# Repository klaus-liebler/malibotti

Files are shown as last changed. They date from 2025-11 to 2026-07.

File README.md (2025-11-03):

# Malibotti
Malibotti represents my initial effort to develop a drawing robot, building upon the concepts of the [ESP32-Drawing-Robot project](https://github.com/MatixYo/ESP32-Drawing-Robot). Key differentiators include a reduced reliance on 3D-printed parts and a custom PCB that functions dually as an electronic carrier and a mechanical structure. Additionally, a dedicated daughterboard with high-precision Hall-effect sensors provides servo arm position data, facilitating closed-loop feedback control for 360° servos.





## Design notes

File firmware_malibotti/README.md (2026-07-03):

# Firmware for Malibotti with 28-BYJ48 stepper motors

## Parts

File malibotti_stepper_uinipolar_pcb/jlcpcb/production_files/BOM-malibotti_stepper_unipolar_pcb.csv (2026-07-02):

Comment | Designator | Footprint | LCSC | Quantity
100R | R2 | R_0805_2012Metric_Pad1.20x1.40mm_HandSolder | C17408 | 1
22R | R8,R9 | R_0402_1005Metric | C25092 | 2
22u | C12,C5,C6 | C_0805_2012Metric | C45783 | 3
5k1 | R1,R26,R3,R4,R7 | R_0402_1005Metric | C25905 | 5
AMS1117 | U3 | SOT-223-3_TabPin2 | C6186 | 1
BTN | SW8 | SW_Push_1P1T_NO_6x6mm_H6.5mm_Reverse | C541960 | 1
Buzzer | BZ1 | XDCR_CMT-7525-80-SMT-TR_handsolder | C49246950 | 1
ESP32-S3-MINI-1 | U5 | ESP32-S2-MINI-1 | C2913206 | 1
RGB3 | D21 | SK6812MINI-E_REV | C5149201 | 1
RST | SW1 | SW_Push_1P1T_NO_6x6mm_H6.5mm_Reverse | C541960 | 1
Servo | J3 | PinHeader_1x03_P2.54mm_Vertical_SMD_Pin1Left | C5160786 | 1
Stepper 1 | J1 | JST_XH_5P_SMD | C7429683 | 1
Stepper 2 | J2 | JST_XH_5P_SMD | C7429683 | 1
TBD62783A | U1 | SSOP-18_4.4x6.5mm_P0.65mm | C4153829 | 1
USB_C_Receptacle_USB2.0_16P | J5 | USB_C_Receptacle_HRO_TYPE-C-31-M-12 | C165948 | 1
u1 | C10,C11,C3,C9 | C_0402_1005Metric | C1525 | 4
MicroSwitchLeft | SW2 | Omron D2F Left Angled |  | 1
Serial | J6 | JST_XH_S4B-XH-A-1_1x04_P2.50mm_Horizontal_SmallerCourtyard |  | 1
MicroSwitchRight | SW3 | Omron D2F Right Angled |  | 1
I2C | J4 | JST_XH_S4B-XH-A-1_1x04_P2.50mm_Horizontal_SmallerCourtyard |  | 1

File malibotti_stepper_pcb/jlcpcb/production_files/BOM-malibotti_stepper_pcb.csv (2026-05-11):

Comment | Designator | Footprint | LCSC | Quantity
100R | R2 | R_0805_2012Metric_Pad1.20x1.40mm_HandSolder | C17408 | 1
10k | R10,R19,R22,R23 | R_0402_1005Metric | C25744 | 4
1k | R11,R12,R13,R14,R15,R16,R17,R18 | R_0402_1005Metric | C11702 | 8
1n | C10,C13,C14,C9 | C_0402_1005Metric | C1523 | 4
1r0 | R20,R21,R5,R6 | R_0805_2012Metric_Pad1.20x1.40mm_HandSolder | C25271 | 4
1u | C1,C4 | C_0402_1005Metric | C52923 | 2
22R | R8,R9 | R_0402_1005Metric | C25092 | 2
22n | C16,C7 | C_0402_1005Metric | C1532 | 2
22u | C12,C17,C2,C5 | C_0805_2012Metric | C45783 | 4
2u2 | C18,C6 | C_0603_1608Metric | C23630 | 2
4k7 | R3,R4 | R_0402_1005Metric | C25900 | 2
5k1 | R1,R24,R25,R7 | R_0402_1005Metric | C25905 | 4
BTN | SW8 | SW_Push_1P1T_NO_6x6mm_H6.5mm_Reverse | C541960 | 1
Buzzer | BZ1 | XDCR_CMT-7525-80-SMT-TR_handsolder | C49246950 | 1
ESP32-C3-MINI-1 | U1 | ESP32-C3-MINI-1 | C2838502 | 1
RGB3 | D21 | SK6812MINI-E_REV | C5149201 | 1
RST | SW1 | SW_Push_1P1T_NO_6x6mm_H6.5mm_Reverse | C541960 | 1
STSPIN220 | U3,U4 | VQFN-16-1EP_3x3mm_P0.5mm_EP1.8x1.8mm | C2150516 | 2
Servo | J3 | PinHeader_1x03_P2.54mm_Vertical_SMD_Pin1Left | C5160786 | 1
Stepper 1 | J1,J2 | JST_XH_5P_SMD | C7429683 | 2
USB_C_Receptacle_USB2.0_16P | J5 | USB_C_Receptacle_HRO_TYPE-C-31-M-12 | C165948 | 1
XC6206PxxxMR | U2 | SOT-23-3 | C5446 | 1
u1 | C11,C15,C3,C8 | C_0402_1005Metric | C1525 | 4
MicroSwitchLeft | SW2 | Omron D2F Left Angled |  | 1
Conn_01x04 | J6 | JST_XH_S4B-XH-A-1_1x04_P2.50mm_Horizontal_SmallerCourtyard |  | 1
MicroSwitchRight | SW3 | Omron D2F Right Angled |  | 1
Conn_01x04 | J4 | JST_XH_S4B-XH-A-1_1x04_P2.50mm_Horizontal_SmallerCourtyard |  | 1
TestPoint | TP1 | TestPoint_THTPad_D1.0mm_Drill0.5mm |  | 1

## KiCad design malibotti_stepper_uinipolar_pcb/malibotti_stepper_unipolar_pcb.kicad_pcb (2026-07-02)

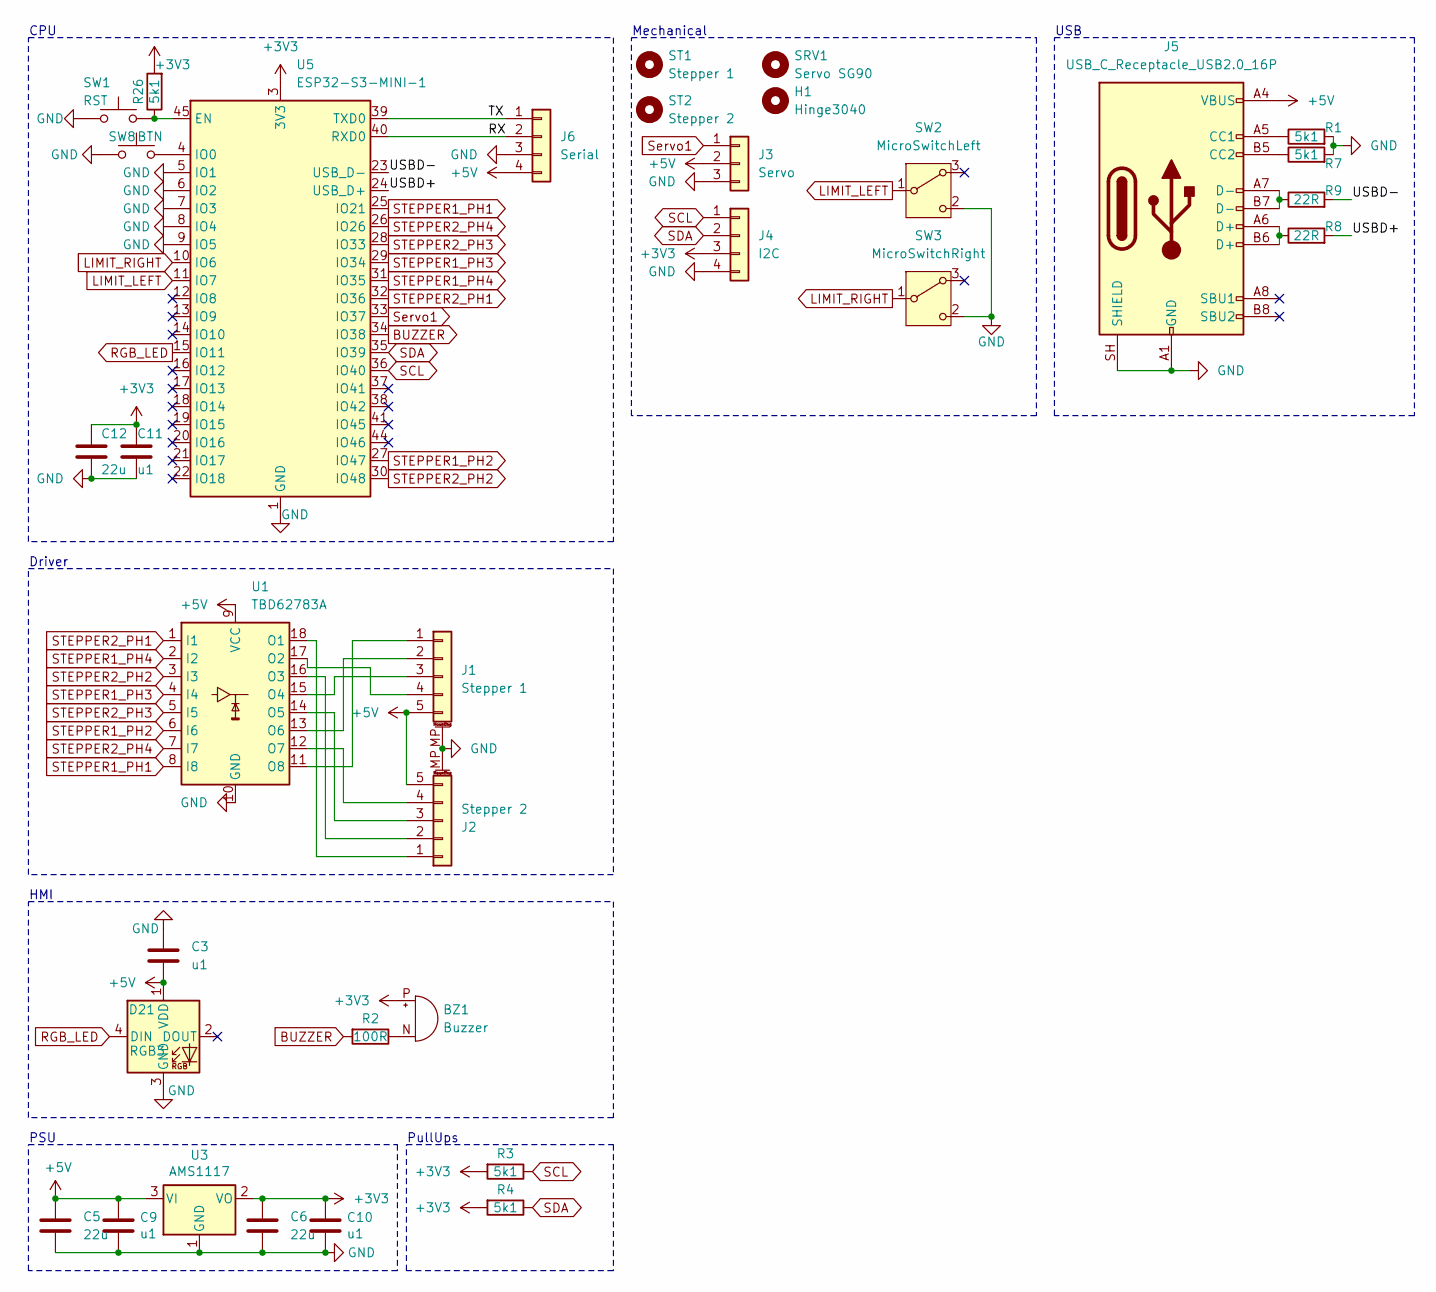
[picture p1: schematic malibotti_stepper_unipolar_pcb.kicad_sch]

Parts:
BZ1: Buzzer; XDCR_CMT-7525-80-SMT-TR_handsolder
C3, C9, C10, C11: u1; C_0402_1005Metric
C5, C6, C12: 22u; C_0805_2012Metric
D21: RGB3; SK6812MINI-E_REV; MPN SK6812MINI-EA
H1: Hinge3040; Hinge_3040
J1: Stepper 1; JST_XH_5P_SMD
J2: Stepper 2; JST_XH_5P_SMD
J3: Servo; PinHeader_1x03_P2.54mm_Vertical_SMD_Pin1Left
J4: I2C; JST_XH_S4B-XH-A-1_1x04_P2.50mm_Horizontal_SmallerCourtyard
J5: USB_C_Receptacle_USB2.0_16P; USB_C_Receptacle_HRO_TYPE-C-31-M-12
J6: Serial; JST_XH_S4B-XH-A-1_1x04_P2.50mm_Horizontal_SmallerCourtyard
R1, R3, R4, R7, R26: 5k1; R_0402_1005Metric
R2: 100R; R_0805_2012Metric_Pad1.20x1.40mm_HandSolder
R8, R9: 22R; R_0402_1005Metric
SRV1: Servo SG90; SG90_vertical_PCB
ST1: Stepper 1; 28BYJ-48
ST2: Stepper 2; 28BYJ-48
SW1: RST; SW_Push_1P1T_NO_6x6mm_H6.5mm_Reverse; MPN TS-1095E-A6B3-D2
SW2: MicroSwitchLeft; Omron D2F Left Angled
SW3: MicroSwitchRight; Omron D2F Right Angled
SW8: BTN; SW_Push_1P1T_NO_6x6mm_H6.5mm_Reverse; MPN TS-1095E-A6B3-D2
U1: TBD62783A; SSOP-18_4.4x6.5mm_P0.65mm
U3: AMS1117; SOT-223-3_TabPin2
U5: ESP32-S3-MINI-1; ESP32-S2-MINI-1

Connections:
+3V3: BZ1.P (+), C6.1, C10.1, C11.1, C12.1, J4.3, R3.2, R4.2, R26.2, U3.2 (VO), U5.3 (3V3)
+5V: C3.1, C5.1, C9.1, D21.1 (VDD), J1.5, J2.5, J3.2, J5.A4 (VBUS), J5.A9 (VBUS), J5.B4 (VBUS), J5.B9 (VBUS), J6.4, U1.9 (VCC), U3.3 (VI)
/RX: J6.2, U5.40 (RXD0)
/TX: J6.1, U5.39 (TXD0)
/USBD+: R8.2, U5.24 (USB_D+)
/USBD-: R9.2, U5.23 (USB_D-)
BUZZER: R2.2, U5.34 (IO38)
GND: C3.2, C5.2, C6.2, C9.2, C10.2, C11.2, C12.2, D21.3 (GND), J1.MP (MountPin), J2.MP (MountPin), J3.3, J4.4, J5.A1 (GND), J5.A12 (GND), J5.B1 (GND), J5.B12 (GND), J5.SH (SHIELD), J6.3, R1.2, R7.2, SW1.2, SW2.2 (C), SW3.2 (C), SW8.1, U1.10 (GND), U3.1 (GND), U5.1 (GND), U5.2 (GND), U5.5 (IO1), U5.6 (IO2), U5.7 (IO3), U5.8 (IO4), U5.9 (IO5), U5.42 (GND), U5.43 (GND), U5.46 (GND), U5.47 (GND), U5.48 (GND), U5.49 (GND), U5.50 (GND), U5.51 (GND), U5.52 (GND), U5.53 (GND), U5.54 (GND), U5.55 (GND), U5.56 (GND), U5.57 (GND), U5.58 (GND), U5.59 (GND), U5.60 (GND), U5.61 (GND), U5.62 (GND), U5.63 (GND), U5.64 (GND), U5.65 (GND)
LIMIT_LEFT: SW2.1 (B), U5.11 (IO7)
LIMIT_RIGHT: SW3.1 (B), U5.10 (IO6)
unnamed: BZ1.N (-), R2.1
unnamed: J1.1, U1.11 (O8)
unnamed: J1.2, U1.13 (O6)
unnamed: J1.3, U1.15 (O4)
unnamed: J1.4, U1.17 (O2)
unnamed: J2.1, U1.18 (O1)
unnamed: J2.2, U1.16 (O3)
unnamed: J2.3, U1.14 (O5)
unnamed: J2.4, U1.12 (O7)
unnamed: J5.A5 (CC1), R1.1
unnamed: J5.B5 (CC2), R7.1
unnamed: J5.A6 (D+), J5.B6 (D+), R8.1
unnamed: J5.A7 (D-), J5.B7 (D-), R9.1
unnamed: R26.1, SW1.1, U5.45 (EN)
unnamed: SW8.2, U5.4 (IO0)
RGB_LED: D21.4 (DIN), U5.15 (IO11)
SCL: J4.1, R3.1, U5.36 (IO40)
SDA: J4.2, R4.1, U5.35 (IO39)
STEPPER1_PH1: U1.8 (I8), U5.25 (IO21)
STEPPER1_PH2: U1.6 (I6), U5.27 (IO47)
STEPPER1_PH3: U1.4 (I4), U5.29 (IO34)
STEPPER1_PH4: U1.2 (I2), U5.31 (IO35)
STEPPER2_PH1: U1.1 (I1), U5.32 (IO36)
STEPPER2_PH2: U1.3 (I3), U5.30 (IO48)
STEPPER2_PH3: U1.5 (I5), U5.28 (IO33)
STEPPER2_PH4: U1.7 (I7), U5.26 (IO26)
Servo1: J3.1, U5.33 (IO37)

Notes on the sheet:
HMI
CPU
Driver
USB
Mechanical
PSU
PullUps

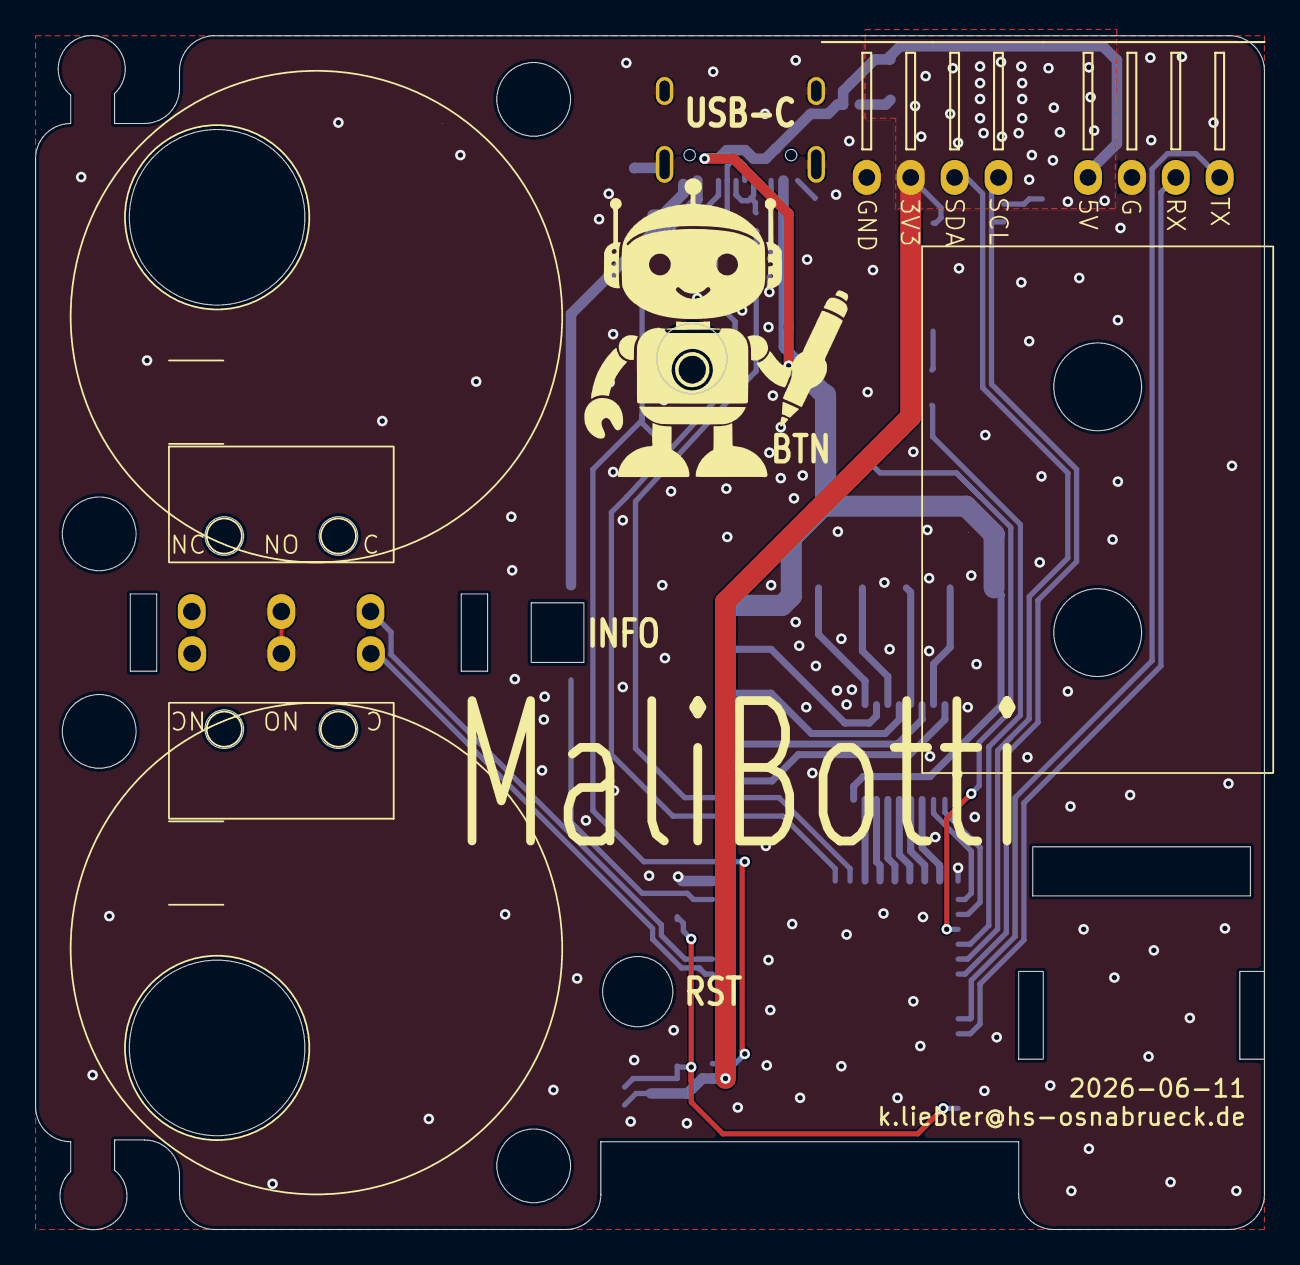
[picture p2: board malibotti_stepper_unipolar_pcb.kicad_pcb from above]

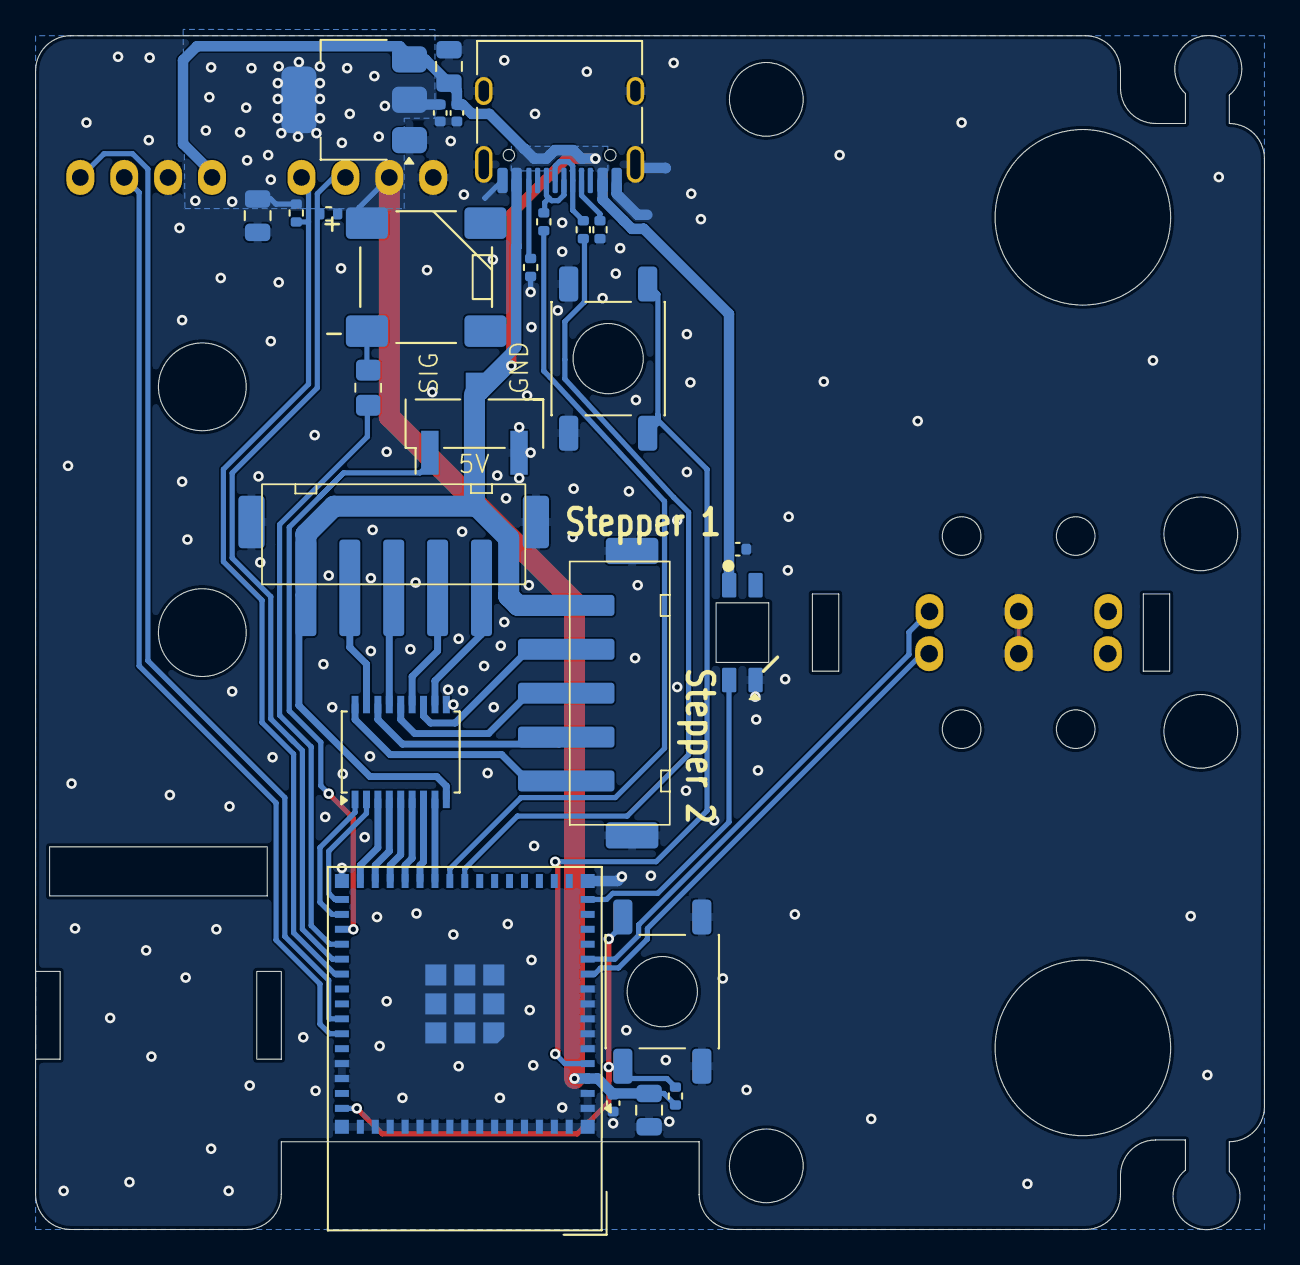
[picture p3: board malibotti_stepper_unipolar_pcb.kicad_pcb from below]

Board: 2 copper layers, 70.0 x 68.0 mm, 34 parts (26 on the bottom side), 37 nets.

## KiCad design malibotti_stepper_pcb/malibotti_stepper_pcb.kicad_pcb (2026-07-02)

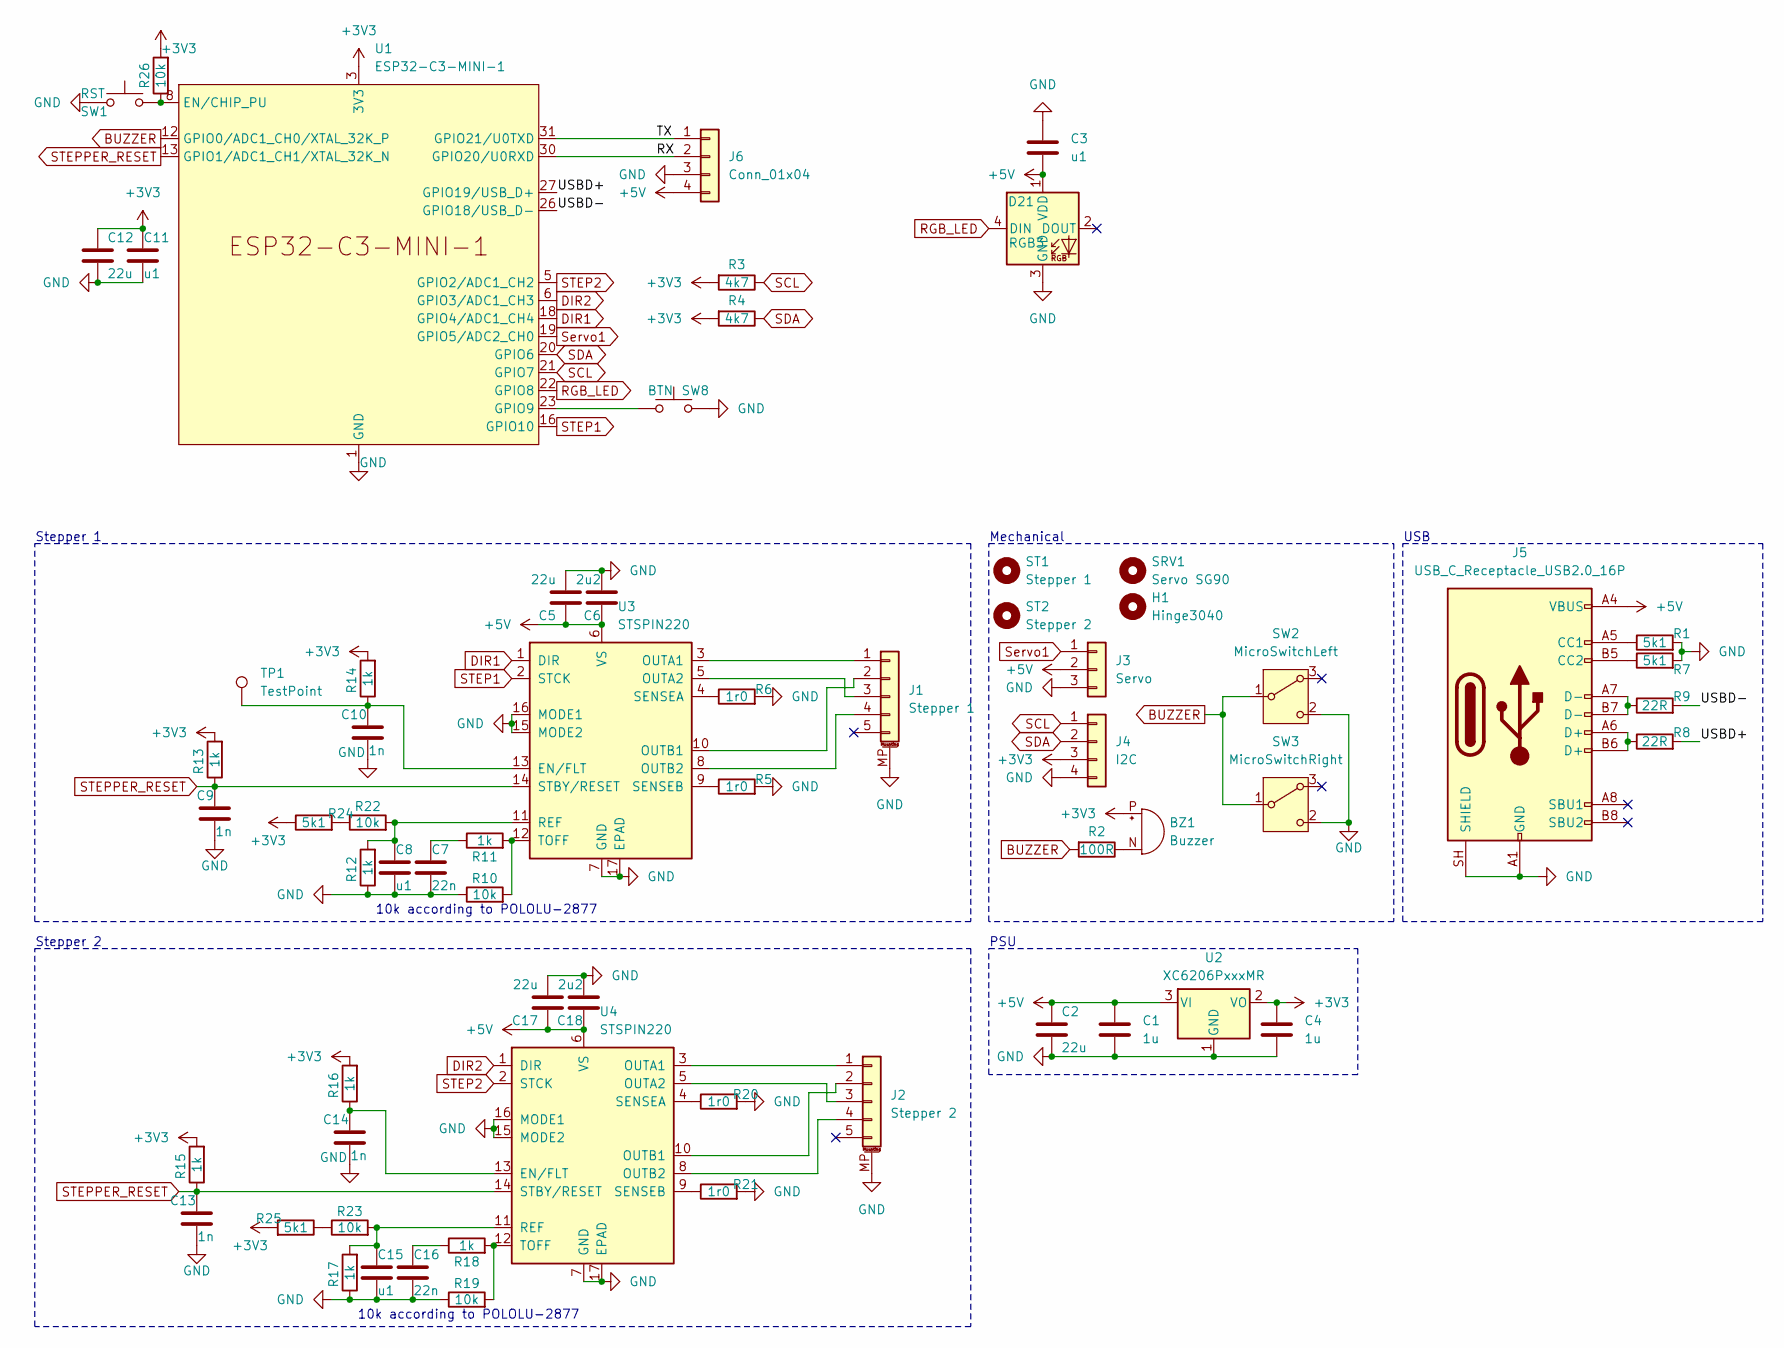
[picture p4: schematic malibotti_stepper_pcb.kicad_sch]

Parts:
BZ1: Buzzer; XDCR_CMT-7525-80-SMT-TR_handsolder
C1, C4: 1u; C_0402_1005Metric
C2, C5, C12, C17: 22u; C_0805_2012Metric
C3, C8, C11, C15: u1; C_0402_1005Metric
C6, C18: 2u2; C_0603_1608Metric
C7, C16: 22n; C_0402_1005Metric
C9, C10, C13, C14: 1n; C_0402_1005Metric
D21: RGB3; SK6812MINI-E_REV; MPN SK6812MINI-EA
H1: Hinge3040; Hinge_3040
J1: Stepper 1; JST_XH_5P_SMD
J2: Stepper 2; JST_XH_5P_SMD
J3: Servo; PinHeader_1x03_P2.54mm_Vertical_SMD_Pin1Left
J4: I2C; JST_XH_S4B-XH-A-1_1x04_P2.50mm_Horizontal_SmallerCourtyard
J5: USB_C_Receptacle_USB2.0_16P; USB_C_Receptacle_HRO_TYPE-C-31-M-12
J6: Conn_01x04; JST_XH_S4B-XH-A-1_1x04_P2.50mm_Horizontal_SmallerCourtyard
R1, R7, R24, R25: 5k1; R_0402_1005Metric
R2: 100R; R_0805_2012Metric_Pad1.20x1.40mm_HandSolder
R3, R4: 4k7; R_0402_1005Metric
R5, R6, R20, R21: 1r0; R_0805_2012Metric_Pad1.20x1.40mm_HandSolder
R8, R9: 22R; R_0402_1005Metric
R10, R19, R22, R23, R26: 10k; R_0402_1005Metric
R11, R12, R13, R14, R15, R16, R17, R18: 1k; R_0402_1005Metric
SRV1: Servo SG90; SG90_vertical_PCB
ST1: Stepper 1; 28BYJ-48
ST2: Stepper 2; 28BYJ-48
SW1: RST; SW_Push_1P1T_NO_6x6mm_H6.5mm_Reverse; MPN TS-1095E-A6B3-D2
SW2: MicroSwitchLeft; Omron D2F Left Angled
SW3: MicroSwitchRight; Omron D2F Right Angled
SW8: BTN; SW_Push_1P1T_NO_6x6mm_H6.5mm_Reverse; MPN TS-1095E-A6B3-D2
TP1: TestPoint; TestPoint_THTPad_D1.5mm_Drill0.7mm
U1: ESP32-C3-MINI-1
U2: XC6206PxxxMR; SOT-23-3
U3, U4: STSPIN220; VQFN-16-1EP_3x3mm_P0.5mm_EP1.8x1.8mm

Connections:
+3V3: BZ1.P (+), C4.1, C11.1, C12.1, J4.3, R3.2, R4.2, R13.2, R14.2, R15.2, R16.2, R24.1, R25.2, R26.2, U1.3 (3V3), U2.2 (VO)
+5V: C1.1, C2.1, C3.1, C5.1, C6.1, C17.1, C18.1, D21.1 (VDD), J3.2, J5.A4 (VBUS), J5.A9 (VBUS), J5.B4 (VBUS), J5.B9 (VBUS), J6.4, U2.3 (VI), U3.6 (VS), U4.6 (VS)
/RX: J6.2, U1.30 (GPIO20/U0RXD)
/TX: J6.1, U1.31 (GPIO21/U0TXD)
/USBD+: R8.2, U1.27 (GPIO19/USB_D+)
/USBD-: R9.2, U1.26 (GPIO18/USB_D-)
BUZZER: R2.2, SW2.1 (B), SW3.1 (B), U1.12 (GPIO0/ADC1_CH0/XTAL_32K_P)
DIR1: U1.18 (GPIO4/ADC1_CH4), U3.1 (DIR)
DIR2: U1.6 (GPIO3/ADC1_CH3), U4.1 (DIR)
GND: C1.2, C2.2, C3.2, C4.2, C5.2, C6.2, C7.2, C8.2, C9.2, C10.2, C11.2, C12.2, C13.2, C14.2, C15.2, C16.2, C17.2, C18.2, D21.3 (GND), J1.MP (MountPin), J2.MP (MountPin), J3.3, J4.4, J5.A1 (GND), J5.A12 (GND), J5.B1 (GND), J5.B12 (GND), J5.SH (SHIELD), J6.3, R1.2, R5.2, R6.2, R7.2, R10.1, R12.1, R17.1, R19.1, R20.2, R21.2, SW1.2, SW2.2 (C), SW3.2 (C), SW8.2, U1.1 (GND), U1.2 (GND), U1.11 (GND), U1.14 (GND), U1.36 (GND), U1.37 (GND), U1.38 (GND), U1.39 (GND), U1.40 (GND), U1.41 (GND), U1.42 (GND), U1.43 (GND), U1.44 (GND), U1.45 (GND), U1.46 (GND), U1.47 (GND), U1.48 (GND), U1.49 (GND), U1.50 (GND), U1.51 (GND), U1.52 (GND), U1.53 (GND), U2.1 (GND), U3.7 (GND), U3.15 (MODE2), U3.16 (MODE1), U3.17 (EPAD), U4.7 (GND), U4.15 (MODE2), U4.16 (MODE1), U4.17 (EPAD)
unnamed: BZ1.N (-), R2.1
unnamed: C7.1, R11.1
unnamed: C16.1, R18.1
unnamed: J1.1, U3.3 (OUTA1)
unnamed: J1.2, U3.10 (OUTB1)
unnamed: J1.3, U3.5 (OUTA2)
unnamed: J1.4, U3.8 (OUTB2)
unnamed: J2.1, U4.3 (OUTA1)
unnamed: J2.2, U4.10 (OUTB1)
unnamed: J2.3, U4.5 (OUTA2)
unnamed: J2.4, U4.8 (OUTB2)
unnamed: J5.A5 (CC1), R1.1
unnamed: J5.B5 (CC2), R7.1
unnamed: J5.A6 (D+), J5.B6 (D+), R8.1
unnamed: J5.A7 (D-), J5.B7 (D-), R9.1
unnamed: R22.1, R24.2
unnamed: R23.1, R25.1
unnamed: R26.1, SW1.1, U1.8 (EN/CHIP_PU)
unnamed: SW8.1, U1.23 (GPIO9)
unnamed: C10.1, R14.1, TP1.1 (1_1), U3.13 (EN/FLT)
unnamed: C8.1, R12.2, R22.2, U3.11 (REF)
unnamed: R6.1, U3.4 (SENSEA)
unnamed: R5.1, U3.9 (SENSEB)
unnamed: R10.2, R11.2, U3.12 (TOFF)
unnamed: C14.1, R16.1, U4.13 (EN/FLT)
unnamed: C15.1, R17.2, R23.2, U4.11 (REF)
unnamed: R20.1, U4.4 (SENSEA)
unnamed: R21.1, U4.9 (SENSEB)
unnamed: R18.2, R19.2, U4.12 (TOFF)
RGB_LED: D21.4 (DIN), U1.22 (GPIO8)
SCL: J4.1, R3.1, U1.21 (GPIO7)
SDA: J4.2, R4.1, U1.20 (GPIO6)
STEP1: U1.16 (GPIO10), U3.2 (STCK)
STEP2: U1.5 (GPIO2/ADC1_CH2), U4.2 (STCK)
STEPPER_RESET: C9.1, C13.1, R13.1, R15.1, U1.13 (GPIO1/ADC1_CH1/XTAL_32K_N), U3.14 (STBY/RESET), U4.14 (STBY/RESET)
Servo1: J3.1, U1.19 (GPIO5/ADC2_CH0)

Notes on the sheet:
USB
Mechanical
Stepper 2
PSU
10k according to POLOLU-2877
Stepper 1

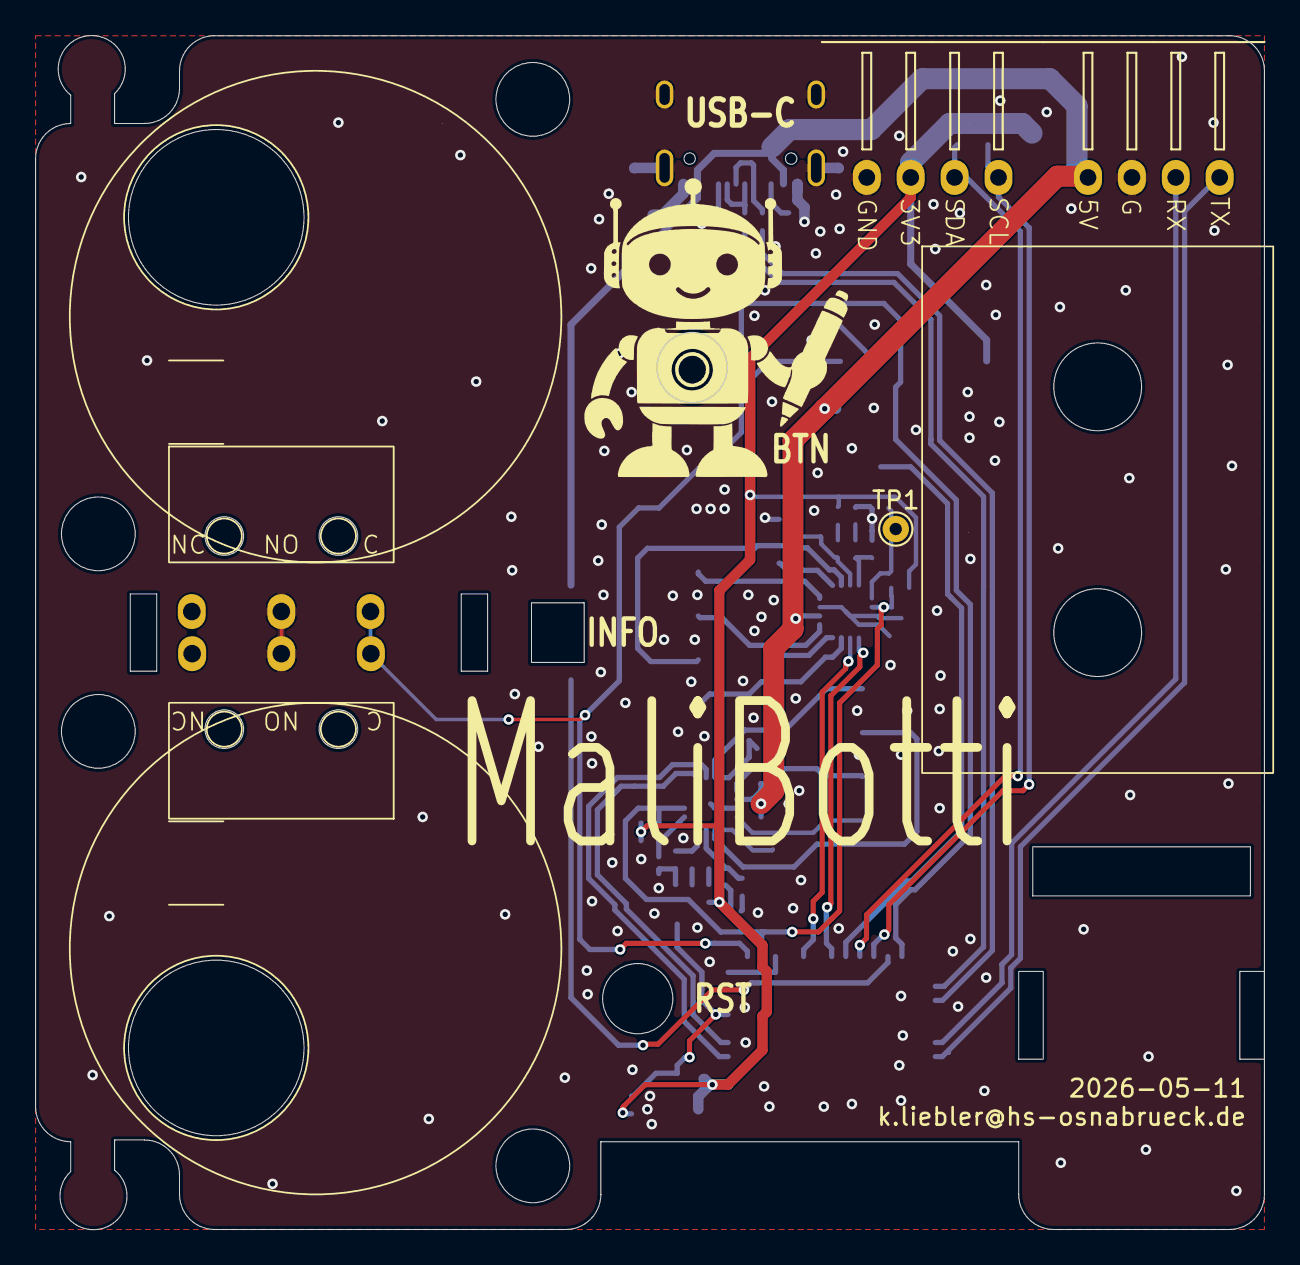
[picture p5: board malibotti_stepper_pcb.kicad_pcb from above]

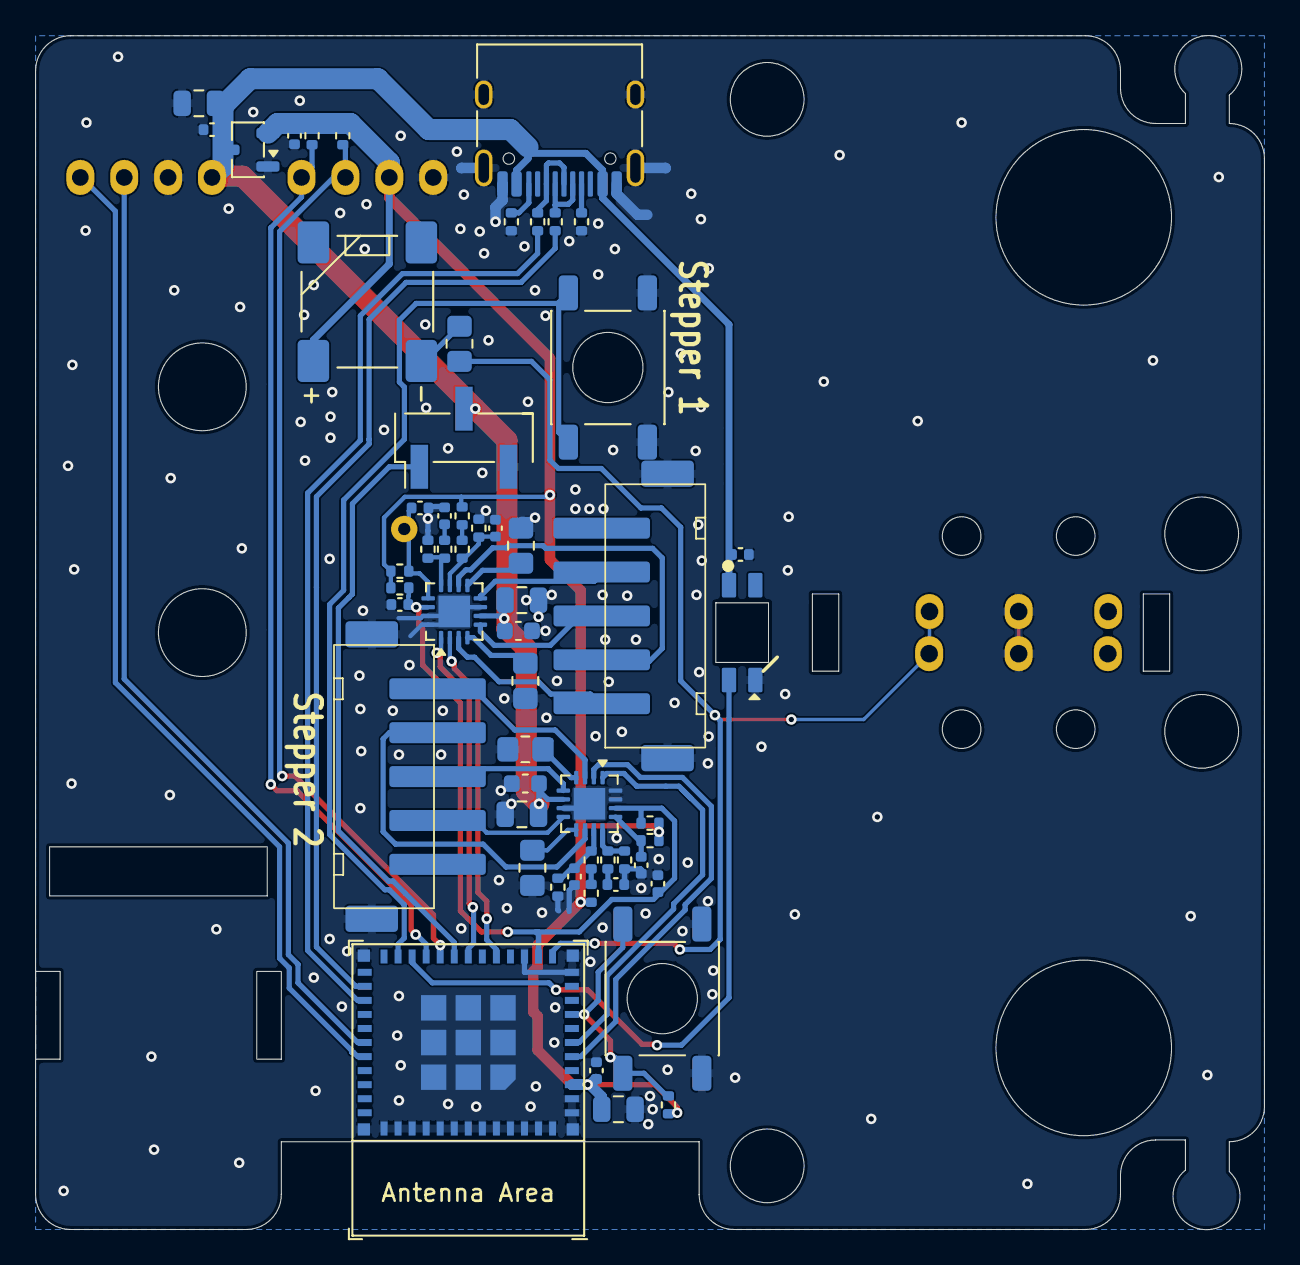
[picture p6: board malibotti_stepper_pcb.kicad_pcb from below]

Board: 2 copper layers, 70.0 x 68.0 mm, 65 parts (55 on the bottom side), 46 nets.

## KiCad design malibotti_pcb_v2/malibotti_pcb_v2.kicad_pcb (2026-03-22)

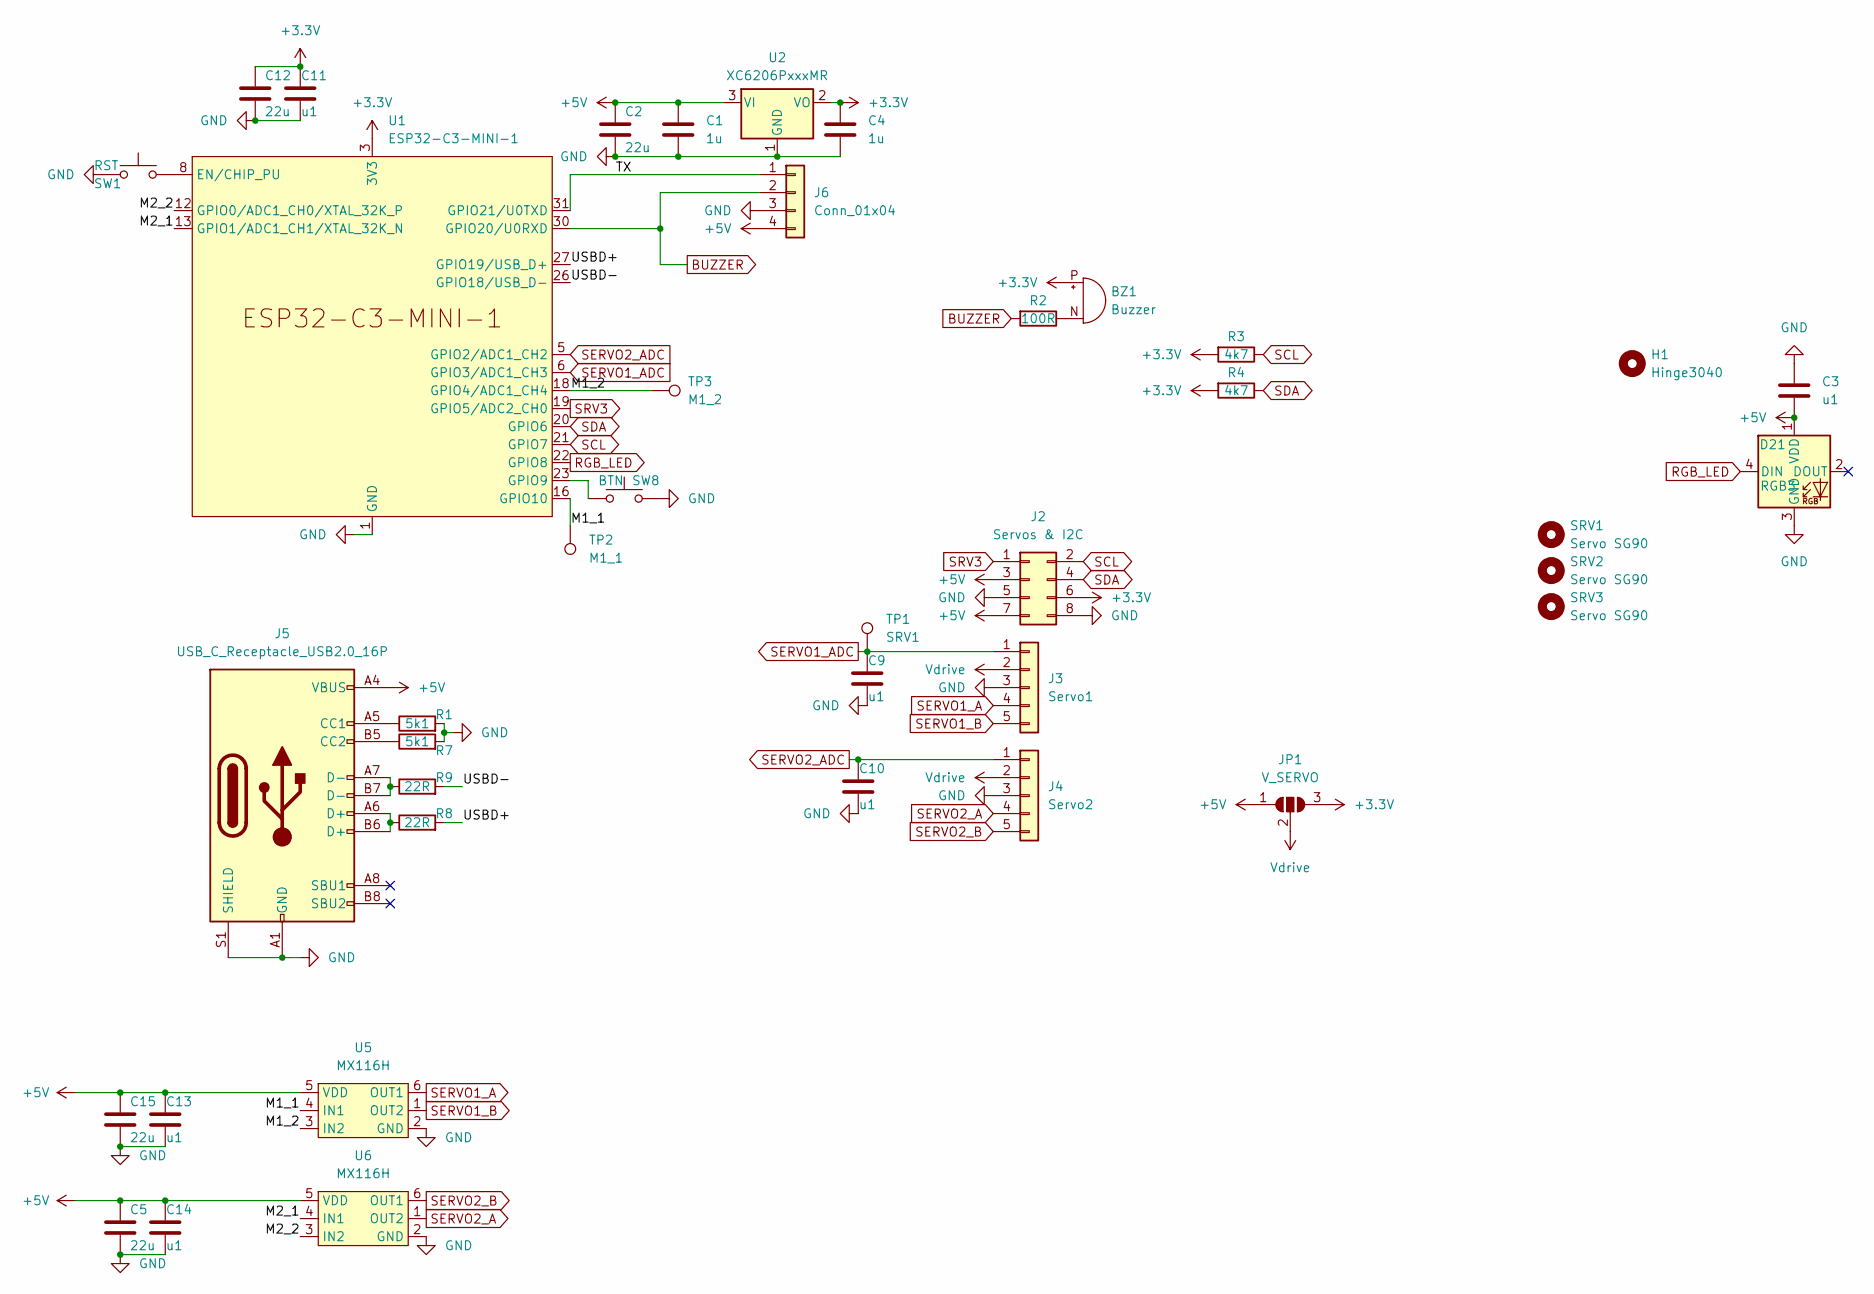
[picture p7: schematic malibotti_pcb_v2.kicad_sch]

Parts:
BZ1: Buzzer; XDCR_CMT-7525-80-SMT-TR_handsolder
C1, C4: 1u; C_0402_1005Metric
C2, C5, C12, C15: 22u; C_0603_1608Metric
C3, C11, C13, C14: u1; C_0402_1005Metric
C9, C10: u1; C_0805_2012Metric_Pad1.18x1.45mm_HandSolder
D21: RGB3; SK6812MINI-E_REV; MPN SK6812MINI-EA
H1: Hinge3040; Hinge_3040
J2: Servos & I2C; PinHeader_2x04_P2.54mm_Vertical_SMD
J3: Servo1; JST_XH_B5B-XH-A_1x05_P2.50mm_Vertical
J4: Servo2; JST_XH_B5B-XH-A_1x05_P2.50mm_Vertical
J5: USB_C_Receptacle_USB2.0_16P; USB_C_Receptacle_HRO_TYPE-C-31-M-12
J6: Conn_01x04; JST_XH_S4B-XH-A-1_1x04_P2.50mm_Horizontal_SmallerCourtyard
JP1: V_SERVO; SolderJumper-3_P1.3mm_Bridged2Bar12_RoundedPad1.0x1.5mm_Num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
R1, R7: 5k1; R_0402_1005Metric
R2: 100R; R_0805_2012Metric_Pad1.20x1.40mm_HandSolder
R3, R4: 4k7; R_0402_1005Metric
R8, R9: 22R; R_0402_1005Metric
SRV1, SRV2: Servo SG90; SG90_PCB
SRV3: Servo SG90; SG90_vertical_PCB
SW1: RST; SW_Push_1P1T_NO_6x6mm_H6.5mm_Reverse; MPN TS-1095E-A6B3-D2
SW8: BTN; SW_Push_1P1T_NO_6x6mm_H6.5mm_Reverse; MPN TS-1095E-A6B3-D2
TP1: SRV1; TestPoint_Pad_1.5x1.5mm
TP2: M1_1; TestPoint_Pad_1.5x1.5mm
TP3: M1_2; TestPoint_Pad_1.5x1.5mm
U1: ESP32-C3-MINI-1
U2: XC6206PxxxMR; SOT-23-3
U5, U6: MX116H; SOT-23-6

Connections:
+3.3V: BZ1.P (+), C4.1, C11.1, C12.1, J2.6, JP1.3 (B), R3.2, R4.2, U1.3 (3V3), U2.2 (VO)
+5V: C1.1, C2.1, C3.1, C5.1, C13.1, C14.1, C15.1, D21.1 (VDD), J2.3, J2.7, J5.A4 (VBUS), J5.A9 (VBUS), J5.B4 (VBUS), J5.B9 (VBUS), J6.4, JP1.1 (A), U2.3 (VI), U5.5 (VDD), U6.5 (VDD)
/M1_1: TP2.1, U1.16 (GPIO10), U5.4 (IN1)
/M1_2: TP3.1, U1.18 (GPIO4/ADC1_CH4), U5.3 (IN2)
/M2_1: U1.13 (GPIO1/ADC1_CH1/XTAL_32K_N), U6.4 (IN1)
/M2_2: U1.12 (GPIO0/ADC1_CH0/XTAL_32K_P), U6.3 (IN2)
/TX: J6.1, U1.31 (GPIO21/U0TXD)
/USBD+: R8.2, U1.27 (GPIO19/USB_D+)
/USBD-: R9.2, U1.26 (GPIO18/USB_D-)
BUZZER: J6.2, R2.2, U1.30 (GPIO20/U0RXD)
GND: C1.2, C2.2, C3.2, C4.2, C5.2, C9.2, C10.2, C11.2, C12.2, C13.2, C14.2, C15.2, D21.3 (GND), J2.5, J2.8, J3.3, J4.3, J5.A1 (GND), J5.A12 (GND), J5.B1 (GND), J5.B12 (GND), J5.S1 (SHIELD), J6.3, R1.2, R7.2, SW1.2, SW8.2, U1.1 (GND), U1.2 (GND), U1.11 (GND), U1.14 (GND), U1.36 (GND), U1.37 (GND), U1.38 (GND), U1.39 (GND), U1.40 (GND), U1.41 (GND), U1.42 (GND), U1.43 (GND), U1.44 (GND), U1.45 (GND), U1.46 (GND), U1.47 (GND), U1.48 (GND), U1.49 (GND), U1.50 (GND), U1.51 (GND), U1.52 (GND), U1.53 (GND), U2.1 (GND), U5.2 (GND), U6.2 (GND)
unnamed: BZ1.N (-), R2.1
unnamed: J5.A5 (CC1), R1.1
unnamed: J5.B5 (CC2), R7.1
unnamed: J5.A6 (D+), J5.B6 (D+), R8.1
unnamed: J5.A7 (D-), J5.B7 (D-), R9.1
unnamed: SW1.1, U1.8 (EN/CHIP_PU)
unnamed: SW8.1, U1.23 (GPIO9)
RGB_LED: D21.4 (DIN), U1.22 (GPIO8)
SCL: J2.2, R3.1, U1.21 (GPIO7)
SDA: J2.4, R4.1, U1.20 (GPIO6)
SERVO1_A: J3.4, U5.6 (OUT1)
SERVO1_ADC: C9.1, J3.1, TP1.1, U1.6 (GPIO3/ADC1_CH3)
SERVO1_B: J3.5, U5.1 (OUT2)
SERVO2_A: J4.4, U6.1 (OUT2)
SERVO2_ADC: C10.1, J4.1, U1.5 (GPIO2/ADC1_CH2)
SERVO2_B: J4.5, U6.6 (OUT1)
SRV3: J2.1, U1.19 (GPIO5/ADC2_CH0)
Vdrive: J3.2, J4.2, JP1.2 (C)

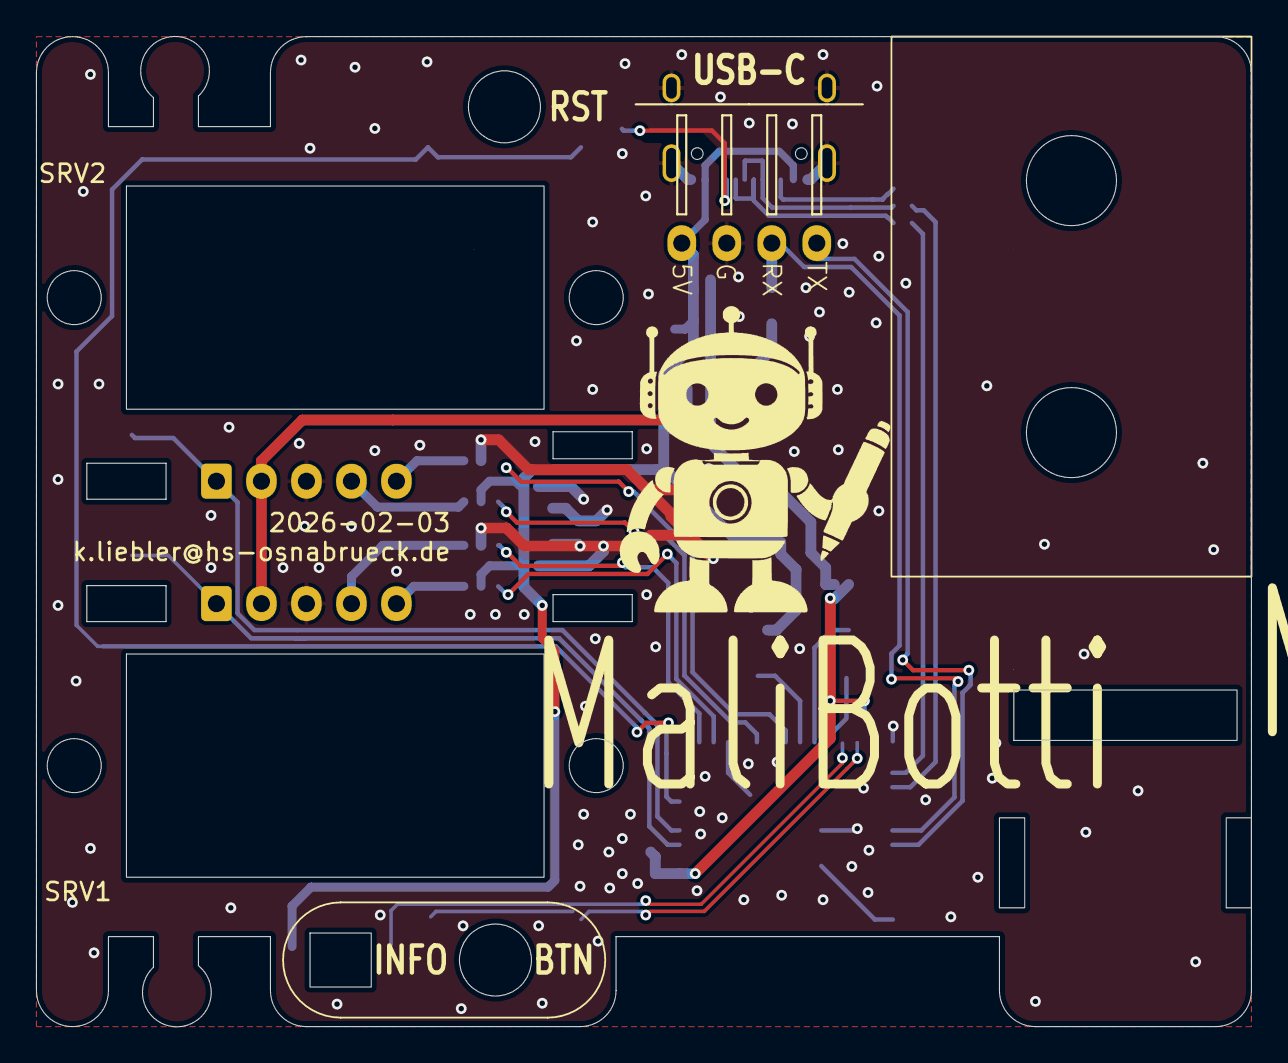
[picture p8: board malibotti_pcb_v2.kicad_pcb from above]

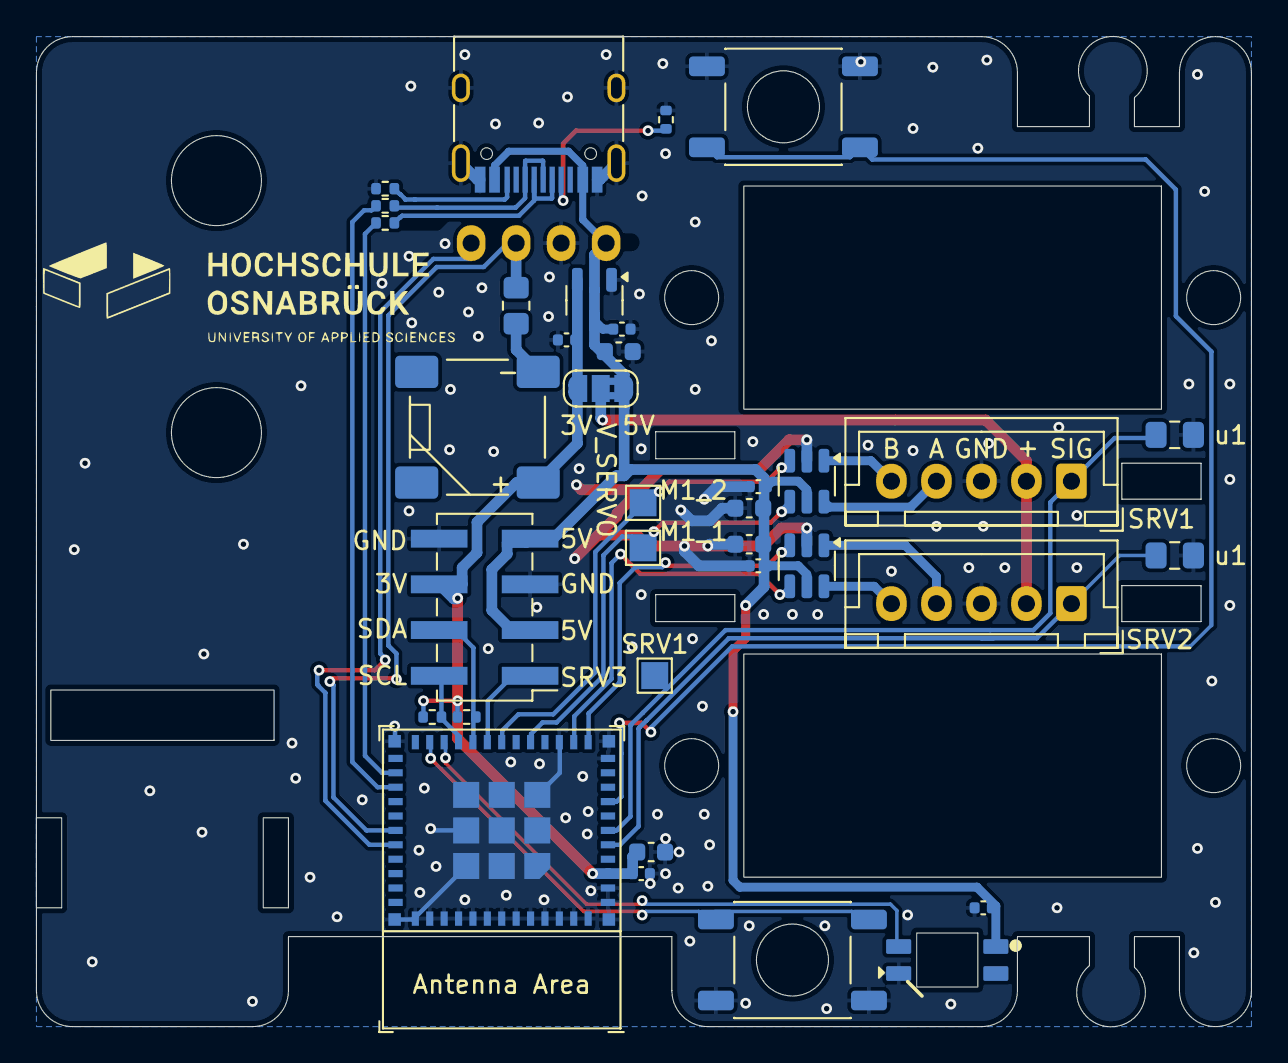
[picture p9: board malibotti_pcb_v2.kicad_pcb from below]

Board: 2 copper layers, 67.5 x 55.0 mm, 40 parts (34 on the bottom side), 29 nets.

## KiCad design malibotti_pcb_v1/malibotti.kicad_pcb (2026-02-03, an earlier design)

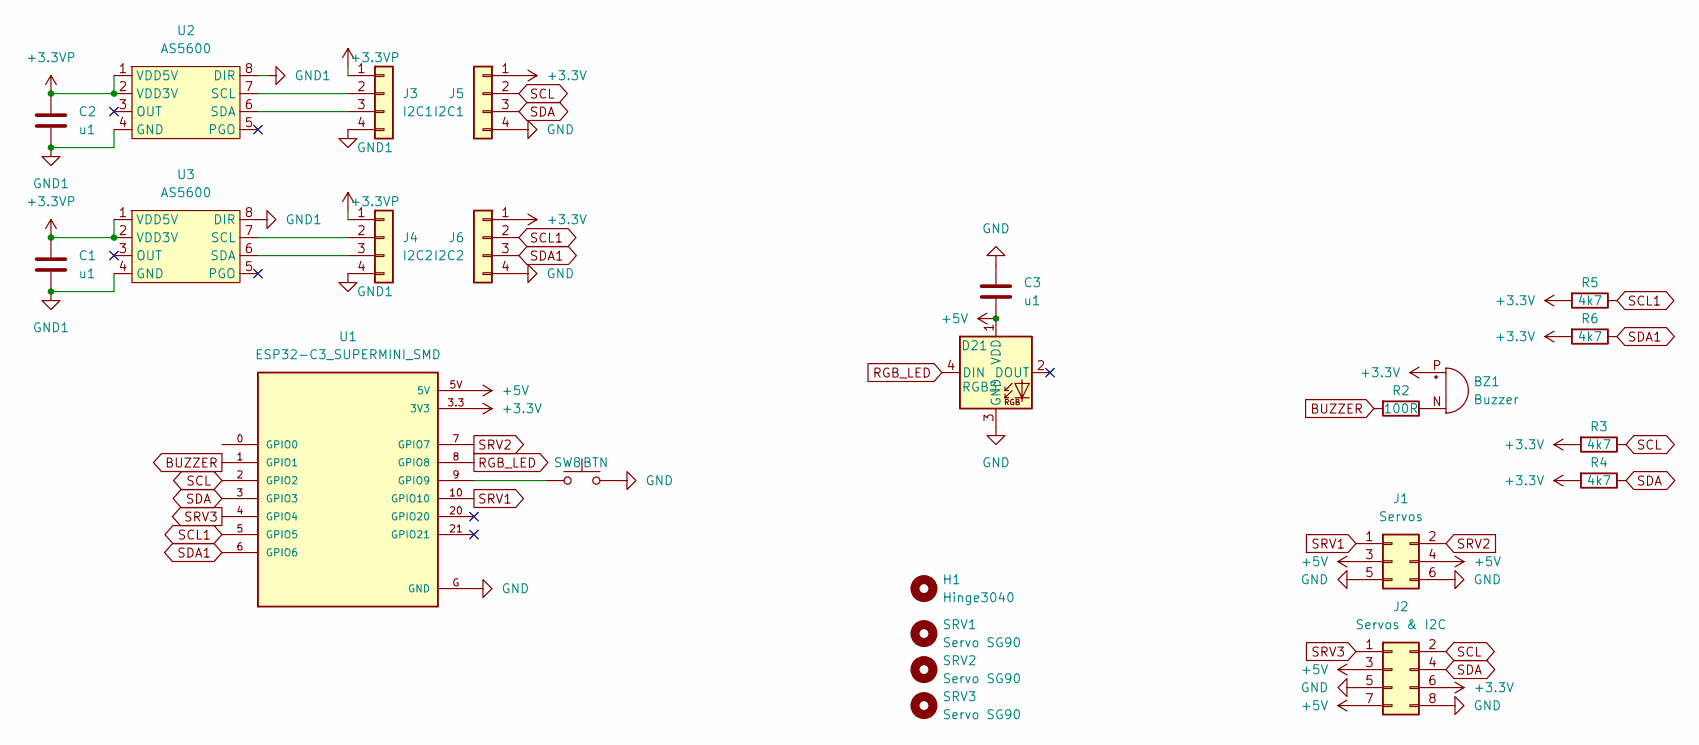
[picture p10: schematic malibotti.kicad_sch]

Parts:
BZ1: Buzzer; XDCR_CMT-7525-80-SMT-TR_handsolder
C1, C2, C3: u1; C_1206_3216Metric_Pad1.33x1.80mm_HandSolder
D21: RGB3; SK6812MINI-E_REV; MPN SK6812MINI-EA
H1: Hinge3040; Hinge_3040
J1: Servos; PinHeader_2x03_P2.54mm_Vertical_SMD
J2: Servos & I2C; PinHeader_2x04_P2.54mm_Vertical_SMD
J3: I2C1; PinHeader_1x04_P2.54mm_Vertical
J4: I2C2; PinHeader_1x04_P2.54mm_Vertical
J5: I2C1; PinSocket_1x04_P2.54mm_Vertical
J6: I2C2; PinSocket_1x04_P2.54mm_Vertical
R2: 100R; R_1206_3216Metric_Pad1.30x1.75mm_HandSolder
R3, R4, R5, R6: 4k7; R_1206_3216Metric_Pad1.30x1.75mm_HandSolder
SRV1, SRV2: Servo SG90; SG90_PCB
SRV3: Servo SG90; SG90_vertical_PCB
SW8: BTN; SW_Push_1P1T_NO_6x6mm_H6.5mm_Reverse; MPN TS-1095E-A6B3-D2
U1: ESP32-C3_SUPERMINI_SMD; MODULE_ESP32-C3_SUPERMINI
U2, U3: AS5600; SOIC-8_3.9x4.9mm_P1.27mm_handsolder

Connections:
+3.3V: BZ1.P (+), J2.6, J5.1, J6.1, R3.2, R4.2, R5.2, R6.2, U1.3.3 (3V3)
+3.3VP: C1.1, C2.1, J3.1, J4.1, U2.1 (VDD5V), U2.2 (VDD3V), U3.1 (VDD5V), U3.2 (VDD3V)
+5V: C3.1, D21.1 (VDD), J1.3, J1.4, J2.3, J2.7, U1.5V
BUZZER: R2.2, U1.1 (GPIO1)
GND: C3.2, D21.3 (GND), J1.5, J1.6, J2.5, J2.8, J5.4, J6.4, SW8.2, U1.G (GND)
GND1: C1.2, C2.2, J3.4, J4.4, U2.4 (GND), U2.8 (DIR), U3.4 (GND), U3.8 (DIR)
unnamed: BZ1.N (-), R2.1
unnamed: J3.2, U2.7 (SCL)
unnamed: J3.3, U2.6 (SDA)
unnamed: J4.2, U3.7 (SCL)
unnamed: J4.3, U3.6 (SDA)
unnamed: SW8.1, U1.9 (GPIO9)
RGB_LED: D21.4 (DIN), U1.8 (GPIO8)
SCL: J2.2, J5.2, R3.1, U1.2 (GPIO2)
SCL1: J6.2, R5.1, U1.5 (GPIO5)
SDA: J2.4, J5.3, R4.1, U1.3 (GPIO3)
SDA1: J6.3, R6.1, U1.6 (GPIO6)
SRV1: J1.1, U1.10 (GPIO10)
SRV2: J1.2, U1.7 (GPIO7)
SRV3: J2.1, U1.4 (GPIO4)

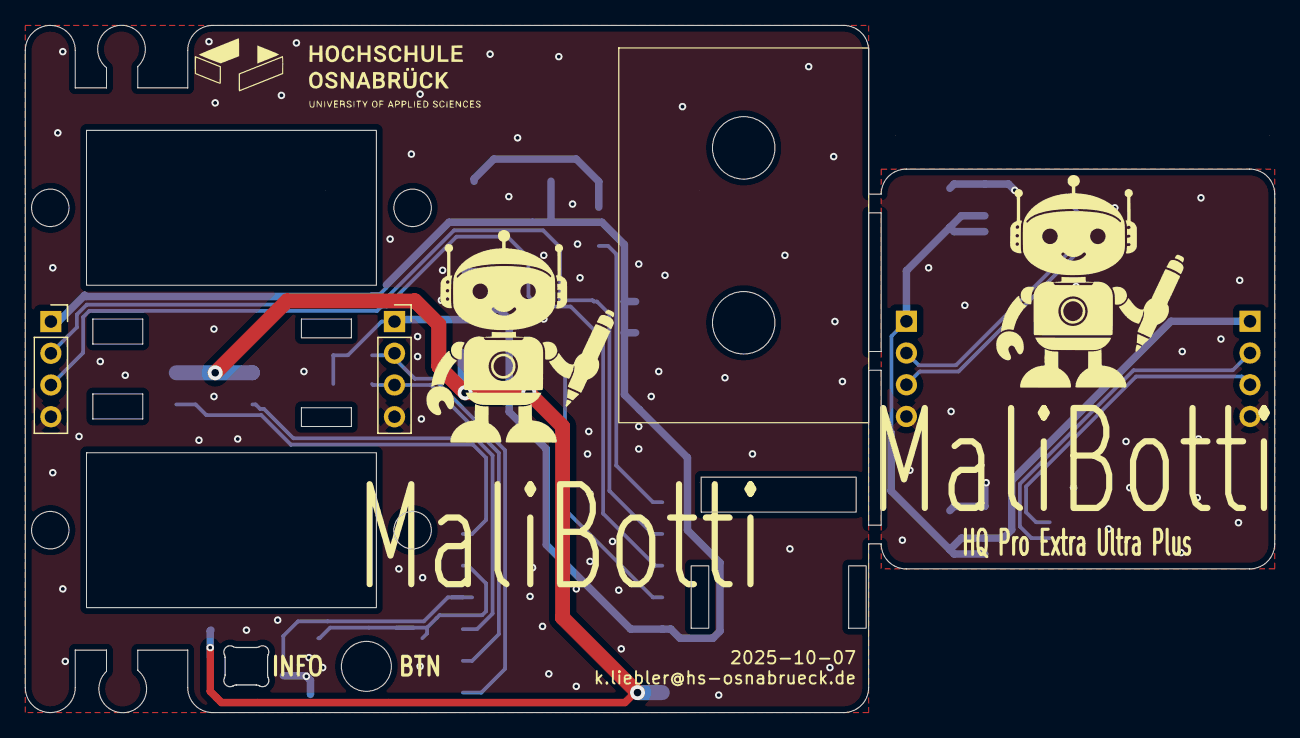
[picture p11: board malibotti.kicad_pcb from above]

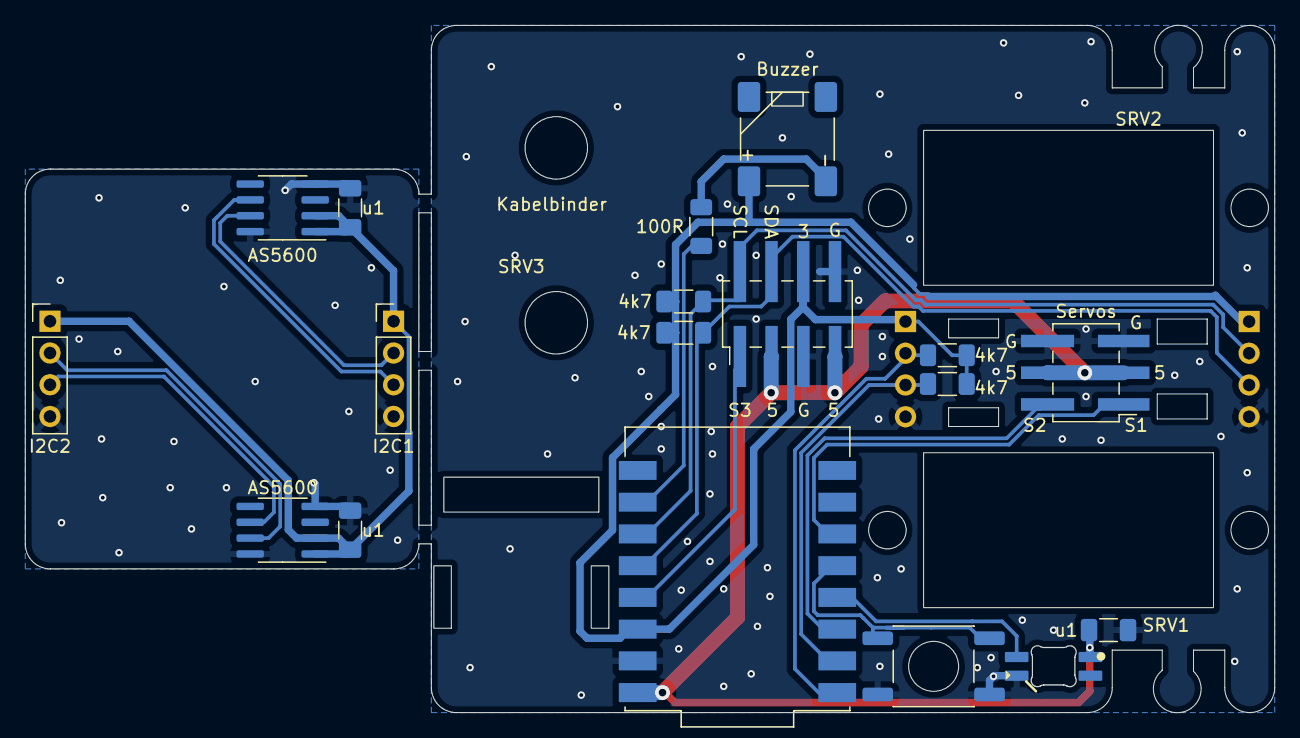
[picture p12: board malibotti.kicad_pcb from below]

Board: 2 copper layers, 100.0 x 55.0 mm, 24 parts (17 on the bottom side), 20 nets.

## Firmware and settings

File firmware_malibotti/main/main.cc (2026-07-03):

#include <stdlib.h>
#include <stdio.h>
#include <string.h>
#include <errno.h>
#include <stdarg.h>
#include <fcntl.h>
#include <array>
#include <sys/types.h>
#include <unistd.h>

#include "sdkconfig.h"
#include "esp_log.h"
#include "esp_mac.h"
#include "esp_system.h"
#include "esp_vfs.h"
#include "freertos/FreeRTOS.h"
#include "freertos/task.h"
#include "rgbled.hh"
#include "esp_rom_gpio.h"

#include "hal/gpio_ll.h"

#include "driver/gpio.h"
#include "driver/uart.h"

#include "buzzer.hh"
#include "listener/echo_message_processor.hh"
#include "listener/rgb_message_processor.hh"
#include "listener/servo_message_processor.hh"
#include "listener/stepper_message_processor.hh"
#include "stepper_unipolar.hh"
#include "usb.hh"

constexpr const char MONITOR_LOG_TAG[] = "monitor";

namespace P
{
  constexpr gpio_num_t BUTTON{GPIO_NUM_0};
  constexpr gpio_num_t LIMIT_RIGHT{GPIO_NUM_6};
  constexpr gpio_num_t LIMIT_LEFT{GPIO_NUM_7};
  constexpr gpio_num_t RGB_LED{GPIO_NUM_11};
  constexpr gpio_num_t STEPPER1_PH1{GPIO_NUM_21};
  constexpr gpio_num_t STEPPER1_PH2{GPIO_NUM_47};
  constexpr gpio_num_t STEPPER1_PH3{GPIO_NUM_34};
  constexpr gpio_num_t STEPPER1_PH4{GPIO_NUM_35};
  constexpr gpio_num_t STEPPER2_PH1{GPIO_NUM_36};
  constexpr gpio_num_t STEPPER2_PH2{GPIO_NUM_48};
  constexpr gpio_num_t STEPPER2_PH3{GPIO_NUM_33};
  constexpr gpio_num_t STEPPER2_PH4{GPIO_NUM_26};
  constexpr gpio_num_t SERVO{GPIO_NUM_37};
  constexpr gpio_num_t BUZZER{GPIO_NUM_38};
  constexpr gpio_num_t SDA{GPIO_NUM_39};
  constexpr gpio_num_t SCL{GPIO_NUM_40};
}

namespace stepper_settings
{
  constexpr uint16_t STEPS_PER_REV = 2048;
  constexpr uint32_t MAX_RPM = 12;
  constexpr TickType_t TURN_PAUSE = pdMS_TO_TICKS(500);
  constexpr bool USE_HALF_STEP = false;
}

constexpr TickType_t CDC_LOG_WRITE_TIMEOUT_TICKS = pdMS_TO_TICKS(20);

/* Blink pattern
 * - 250 ms  : device not mounted
 * - 1000 ms : device mounted
 * - 2500 ms : device is suspended
 */
RGBLED::BlinkPattern NOT_MOUNTED(CRGB::Red, 250, CRGB::Black, 250);
RGBLED::BlinkPattern MOUNTED(CRGB::Green, 1000, CRGB::Black, 1000);
RGBLED::BlinkPattern SUSPENDED(CRGB::Blue, 250, CRGB::Black, 2250);
RGBLED::MultipleFlashesPattern USB_INIT_FAILED(CRGB::Red, 2);

RGBLED::M<1, RGBLED::DeviceType::WS2812> s_board_led;
BUZZER::M s_buzzer;
ISendBackInterface *s_sendBack;
int (*s_previous_log_vprintf)(const char *, va_list) = nullptr;

using Stepper1 = StepperUnipolar<P::STEPPER1_PH1,
                                 P::STEPPER1_PH3,
                                 P::STEPPER1_PH2,
                                 P::STEPPER1_PH4,
                                 stepper_settings::STEPS_PER_REV,
                                 false,
                                 stepper_settings::USE_HALF_STEP>;

using Stepper2 = StepperUnipolar<P::STEPPER2_PH1,
                                 P::STEPPER2_PH3,
                                 P::STEPPER2_PH2,
                                 P::STEPPER2_PH4,
                                 stepper_settings::STEPS_PER_REV,
                                 false,
                                 stepper_settings::USE_HALF_STEP>;

static Stepper1 s_stepper1;
static Stepper2 s_stepper2;

static std::array<IMessageProcessor *, 5> message_processors{
  new listener::EchoMessageProcessor(),
  new listener::RGBMessageProcessor(s_board_led),
  new listener::ServoMessageProcessor(P::SERVO),
  new listener::StepperMessageProcessor<0x0004>(s_stepper1),
  new listener::StepperMessageProcessor<0x0005>(s_stepper2)
};

static void process_vendor_binary_message(const uint8_t msg[usb_bridge::kBinaryMsgSize])
{
  uint16_t const name_space = static_cast<uint16_t>(msg[0] | (static_cast<uint16_t>(msg[1]) << 8));
  uint16_t const message_id = static_cast<uint16_t>(msg[2] | (static_cast<uint16_t>(msg[3]) << 8));
  uint8_t const *payload = msg + 4;

  IMessageProcessor *message_listener = nullptr;
  for (auto *processor : message_processors)
  {
    if (processor != nullptr && processor->GetNamespace() == name_space)
    {
      message_listener = processor;
      break;
    }
  }

  if (message_listener == nullptr)
  {
    return;
  }

  message_listener->Handle(*s_sendBack, message_id, payload);
}

static void processing_task(void *context)
{
  (void)context;

  while (true)
  {
    s_board_led.Refresh();
    s_buzzer.Loop();
    uint32_t const now_ms = static_cast<uint32_t>(esp_timer_get_time() / 1000);
    for (auto *processor : message_processors)
    {
      if (processor != nullptr)
      {
        processor->Loop(*s_sendBack, now_ms);
      }
    }
    vTaskDelay(pdMS_TO_TICKS(10));
  }
}

extern "C" void app_main(void)
{
  s_sendBack = new usb_bridge::VendorSendBack();
  usb_bridge::SetVendorMessageHandler(process_vendor_binary_message);

  s_stepper1.Init();
  s_stepper2.Init();

  s_board_led.Begin(SPI2_HOST, P::RGB_LED);
  s_buzzer.Begin(P::BUZZER);
  s_buzzer.PlaySong(1);

  for (auto *processor : message_processors)
  {
    if (processor != nullptr)
    {
      processor->Setup(*s_sendBack, 0);
    }
  }

  esp_rom_gpio_pad_select_gpio(P::BUTTON);
  gpio_set_direction(P::BUTTON, GPIO_MODE_INPUT);
  gpio_set_pull_mode(P::BUTTON, GPIO_PULLUP_ONLY);

  ESP_ERROR_CHECK(usb_bridge::Init());

  xTaskCreate(processing_task, "processing", 4096, nullptr, tskIDLE_PRIORITY + 2, nullptr);

  while (true)
  {
    ESP_LOGI(
        MONITOR_LOG_TAG,
        "mntd=%d sspnd=%d cdc_cnctd=%d cdc_rx=%u cdc_tx_free=%u btn=%d heap=%lu",
        tud_mounted() ? 1 : 0,
        tud_suspended() ? 1 : 0,
        tud_cdc_connected() ? 1 : 0,
        static_cast<unsigned>(tud_cdc_available()),
        static_cast<unsigned>(tud_cdc_write_available()),
        !gpio_get_level(P::BUTTON),
        static_cast<unsigned long>(esp_get_free_heap_size()));
    vTaskDelay(pdMS_TO_TICKS(3000));
  }
}

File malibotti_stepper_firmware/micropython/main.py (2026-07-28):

"""ESP32 MicroPython - zwei 28BYJ-48 Schrittmotoren (ULN2003) abwechselnd rechts/links drehen.

Pinbelegung analog zu src/main.cpp
"""

from machine import Pin
import time

STEPS_PER_REVOLUTION = 2048

ROTATE_RPM = 12
ROTATE_PAUSE_MS = 600

# Halbschritt-Sequenz fuer 28BYJ-48 (IN1, IN2, IN3, IN4)
HALFSTEP_SEQ = (
    (1, 0, 0, 0),
    (1, 1, 0, 0),
    (0, 1, 0, 0),
    (0, 1, 1, 0),
    (0, 0, 1, 0),
    (0, 0, 1, 1),
    (0, 0, 0, 1),
    (1, 0, 0, 1),
)


class Stepper:
    def __init__(self, phase1, phase2, phase3, phase4, steps_per_revolution=STEPS_PER_REVOLUTION):
        self._pins = (
            Pin(phase1, Pin.OUT),
            Pin(phase2, Pin.OUT),
            Pin(phase3, Pin.OUT),
            Pin(phase4, Pin.OUT),
        )
        self._steps_per_revolution = steps_per_revolution
        self._seq_index = 0
        self._step_delay_ms = 2
        self._release()

    def set_speed(self, rpm):
        steps_per_minute = self._steps_per_revolution * rpm
        self._step_delay_ms = max(1, 60000 // steps_per_minute)

    def _write_step(self, seq_index):
        values = HALFSTEP_SEQ[seq_index % len(HALFSTEP_SEQ)]
        for pin, value in zip(self._pins, values):
            pin.value(value)

    def _release(self):
        for pin in self._pins:
            pin.value(0)

    def step(self, steps):
        direction = 1 if steps >= 0 else -1
        for _ in range(abs(steps)):
            self._seq_index = (self._seq_index + direction) % len(HALFSTEP_SEQ)
            self._write_step(self._seq_index)
            time.sleep_ms(self._step_delay_ms)
        self._release()


# Stepper 1
stepper1 = Stepper(21, 47, 34, 35)

# Stepper 2
stepper2 = Stepper(36, 48, 33, 26)

stepper1.set_speed(ROTATE_RPM)
stepper2.set_speed(ROTATE_RPM)

print("ESP32 MicroPython gestartet")

while True:
    print("Stepper 1 rechts")
    stepper1.step(STEPS_PER_REVOLUTION)
    time.sleep_ms(ROTATE_PAUSE_MS)

    print("Stepper 1 links")
    stepper1.step(-STEPS_PER_REVOLUTION)
    time.sleep_ms(ROTATE_PAUSE_MS)

    print("Stepper 2 rechts")
    stepper2.step(STEPS_PER_REVOLUTION)
    time.sleep_ms(ROTATE_PAUSE_MS)

    print("Stepper 2 links")
    stepper2.step(-STEPS_PER_REVOLUTION)
    time.sleep_ms(ROTATE_PAUSE_MS)

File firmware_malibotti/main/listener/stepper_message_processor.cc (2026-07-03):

#include "listener/stepper_message_processor.hh"

#include "esp_log.h"

namespace listener {

namespace {

constexpr char kStepperLogTag[] = "StepperMessageProcessor";

}  // namespace

template <uint16_t kNamespaceStepper>
void StepperMessageProcessor<kNamespaceStepper>::Setup(ISendBackInterface& context, uint32_t now_ms) {
  (void)context;
  (void)now_ms;

  if (setup_done_.load()) {
    return;
  }

  queue_ = xQueueCreate(kQueueCapacity, sizeof(StepperTurnJob));
  if (queue_ == nullptr) {
    ESP_LOGE(kStepperLogTag, "Failed to create stepper queue");
    return;
  }

  BaseType_t const created = xTaskCreate(
      &StepperMessageProcessor::WorkerTaskTrampoline,
      "stepper_worker",
      4096,
      this,
      tskIDLE_PRIORITY + 2,
      &worker_task_handle_);
  if (created != pdPASS) {
    ESP_LOGE(kStepperLogTag, "Failed to create stepper worker task");
    vQueueDelete(queue_);
    queue_ = nullptr;
    return;
  }

  setup_done_.store(true);
}

template <uint16_t kNamespaceStepper>
void StepperMessageProcessor<kNamespaceStepper>::Handle(ISendBackInterface& context, uint16_t message_id, const uint8_t* payload) {
  if (payload == nullptr) {
    return;
  }

  switch (message_id) {
    case kMessageEnqueueTurn:
      HandleEnqueueTurn(message_id, payload);
      break;
    case kMessageGetPendingCount:
      HandleGetPendingCount(context, message_id);
      break;
    default:
      break;
  }
}

template <uint16_t kNamespaceStepper>
uint16_t StepperMessageProcessor<kNamespaceStepper>::GetNamespace() const {
  return kNamespaceStepper;
}

template <uint16_t kNamespaceStepper>
int32_t StepperMessageProcessor<kNamespaceStepper>::DecodeI32Le(const uint8_t* payload) {
  return static_cast<int32_t>(
      static_cast<uint32_t>(payload[0]) |
      (static_cast<uint32_t>(payload[1]) << 8) |
      (static_cast<uint32_t>(payload[2]) << 16) |
      (static_cast<uint32_t>(payload[3]) << 24));
}

template <uint16_t kNamespaceStepper>
uint16_t StepperMessageProcessor<kNamespaceStepper>::DecodeU16Le(const uint8_t* payload) {
  return static_cast<uint16_t>(
      static_cast<uint16_t>(payload[0]) |
      (static_cast<uint16_t>(payload[1]) << 8));
}

template <uint16_t kNamespaceStepper>
void StepperMessageProcessor<kNamespaceStepper>::EncodeU16Le(uint8_t* payload, uint16_t value) {
  payload[0] = static_cast<uint8_t>(value & 0xFF);
  payload[1] = static_cast<uint8_t>((value >> 8) & 0xFF);
}

template <uint16_t kNamespaceStepper>
void StepperMessageProcessor<kNamespaceStepper>::WorkerTaskTrampoline(void* context) {
  auto* self = static_cast<StepperMessageProcessor<kNamespaceStepper>*>(context);
  self->WorkerTask();
}

template <uint16_t kNamespaceStepper>
void StepperMessageProcessor<kNamespaceStepper>::WorkerTask() {
  while (true) {
    StepperTurnJob job{};
    if (xQueueReceive(queue_, &job, portMAX_DELAY) != pdTRUE) {
      continue;
    }

    job_active_.store(true);

    float const rpm = static_cast<float>((job.rpm_x10 == 0) ? kDefaultRpmX10 : job.rpm_x10) / 10.0f;
    stepper_step_fn_(stepper_, job.steps, rpm);

    job_active_.store(false);
  }
}

template <uint16_t kNamespaceStepper>
bool StepperMessageProcessor<kNamespaceStepper>::EnqueueTurn(const StepperTurnJob& job) {
  if (queue_ == nullptr) {
    return false;
  }
  return xQueueSend(queue_, &job, 0) == pdTRUE;
}

template <uint16_t kNamespaceStepper>
uint16_t StepperMessageProcessor<kNamespaceStepper>::PendingCount() const {
  uint16_t pending = 0;
  if (queue_ != nullptr) {
    pending = static_cast<uint16_t>(uxQueueMessagesWaiting(queue_));
  }
  if (job_active_.load()) {
    ++pending;
  }
  return pending;
}

template <uint16_t kNamespaceStepper>
void StepperMessageProcessor<kNamespaceStepper>::HandleEnqueueTurn(uint16_t message_id, const uint8_t* payload) {
  (void)message_id;

  StepperTurnJob const job{
      DecodeI32Le(payload),
      DecodeU16Le(payload + 4),
  };

  if (job.steps == 0) {
    return;
  }

  if (!EnqueueTurn(job)) {
    ESP_LOGW(kStepperLogTag, "Stepper queue full. Dropping job steps=%ld", static_cast<long>(job.steps));
  }
}

template <uint16_t kNamespaceStepper>
void StepperMessageProcessor<kNamespaceStepper>::HandleGetPendingCount(ISendBackInterface& context, uint16_t message_id) {
  uint8_t response[60] = {};
  EncodeU16Le(response, PendingCount());
  (void)context.Send(kNamespaceStepper, message_id, response);
}

template class StepperMessageProcessor<0x0004>;
template class StepperMessageProcessor<0x0005>;

}  // namespace listener

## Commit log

2025-10-12 Malibotti as ordered @ JLCPCB
    [BOM-malibotti.csv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]
2026-02-03 moved files
    [BOM-malibotti.csv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]
2026-02-10 PCB v2
    [malibotti_pcb_v2.kicad_pcb, malibotti_pcb_v2.kicad_sch]
2026-02-24 Added serial port
    [malibotti_pcb_v2.kicad_pcb]
2026-03-22 Malibotti Stepper + renaming
    [BOM-malibotti.csv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]
2026-04-01 Malibotti WIP
    [malibotti_stepper_pcb.kicad_pcb, malibotti_stepper_pcb.kicad_sch]
2026-04-08 Malibotti Stepper Release Candidate
    [malibotti_stepper_pcb.kicad_pcb]
2026-04-13 Limit Switch
    [malibotti_stepper_pcb.kicad_pcb, malibotti_stepper_pcb.kicad_sch]
2026-04-22 Minor improvements
    [malibotti_stepper_pcb.kicad_pcb]
2026-05-11 update to Kicad 10
    [malibotti_stepper_pcb.kicad_pcb]
2026-05-11 Malibotti stepper as ordered @ JLCPCB
    [BOM-malibotti_stepper_pcb.csv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]
2026-07-02 Malibotti unipolar as ordered @ JLCPCB
    [BOM-malibotti_stepper_unipolar_pcb.csv, malibotti_stepper_pcb.kicad_pcb, malibotti_stepper_pcb.kicad_sch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]
2026-07-03 Test mit Arduino-Stepper
    [malibotti_stepper_pcb.kicad_sch]
2026-07-03 WebControlled Malibotti with working steppers
    [malibotti_stepper_unipolar_pcb.kicad_sch]
2026-07-28 Revert "Merge branch 'master' of https://github.com/klaus-liebler/malibotti"
    This reverts commit e32d648555214dd673c0994955a1c8da412dea1e, reversing
    changes made to 1ab6b0115ca777e0c305d243220f439b6c76d3ff.
    [BOM-malibotti_stepper_unipolar_pcb.csv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]
